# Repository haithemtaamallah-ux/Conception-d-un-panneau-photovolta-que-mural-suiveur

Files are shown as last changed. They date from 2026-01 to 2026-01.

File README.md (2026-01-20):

# Wall-Mounted Photovoltaic Panel Design with Solar Tracking Device

**End-of-Year Project Report**  
**2nd Year Mechanical Engineering**  
**National Engineering School of Tunis (ENIT)**  
**University of Tunis El Manar**  
**Academic Year: 2025/2026**

**Prepared by:**  
- Snoussi Syrine Sara  
- Taamallah Haithem  

**Supervised by:**  
Mr. Jemmali Mohamed

## 📌 Project Context

This project aims to design a **wall-mounted photovoltaic panel** for self-consumption, equipped with a **single-axis solar tracking device** to optimize the panel’s orientation throughout the day and maximize the amount of solar energy harvested.

## 🎯 Main Objectives

- Study the Tunisian energy context and the operation of photovoltaic cells  
- Geometrically model the solar path and calculate the angle of incidence  
- Develop Python code to simulate irradiance and annual energy yield for different fixed and tracking inclinations  
- Mechanically design a single-axis tracker actuated by an electric actuator (CAD modeling in CATIA V5)  
- Dimension the components and validate the mechanism’s kinematics  

## 🗂 Repository Structure

*(Details to be added in the GitHub repository)*

## 📊 Detailed Report Content

### 1. Context and Problem Statement
- Current energy situation in Tunisia  
- Structure and operation of a PV cell  
- Effect of the incidence angle on energy production  

### 2. Numerical Modeling and Simulation
- Geometrical model of solar movement (declination δ, hour angle ω)  
- Calculation of incidence angle θ  
- Python algorithm + validation of results  
- Annual energy comparison: fixed vs. tracking panel (different β values)  

### 3. Mechanical Design of the Tracker
- Choice of tracker type: single-axis (rotation β)  
- Kinematic solutions studied:  
  - Motors / couplings  
  - Rack and pinion  
  - Pulley-belt systems  
  - **Electric actuator + linkages** (selected solution)  
- Overall panel and mechanism sizing  
- Detailed 3D modeling in CATIA V5  
- Exploded views, assemblies, functional clearances  

## 🛠 Technologies & Tools Used

- **CAD**: CATIA V5  
- **Programming**: Python (numpy, matplotlib, astronomical calculations)  
- **Key Concepts**: Direct/diffuse radiation, solar tracking, kinematics, mechanical sizing  

## Project Visual Overview

<p align="center">
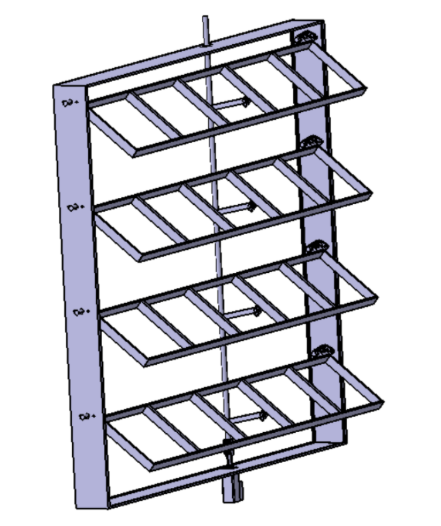
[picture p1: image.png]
Overall system diagram
  
  <br><em>Overall diagram of the panel with single-axis tracker</em>
</p>

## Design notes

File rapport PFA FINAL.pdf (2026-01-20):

République Tunisienne
Ministère de l’Enseignement Supérieur et de la Recherche Scientifique Université de Tunis El Manar École Nationale d’Ingénieurs de Tunis

# Rapport de Projet De Fin D’année

## Conception d’un panneau photovoltaïque mural avec dispositif suiveur

Elaboré par :

### Snoussi Syrine Sara

### Taamallah Haithem

Encadré par :

### MR. Jemmali Mohamed

2

### ème Année Génie Mécanique

Année universitaire : 2025/2026

Projet De Fin D’année

# Remerciements

Nous tenons à exprimer nos sincères remerciements à Monsieur Jemmali Mohamed pour son encadrement attentif et ses conseils précieux tout au long de ce projet. Sa disponibilité, son expertise technique et sa capacité à nous guider avec clarté ont grandement facilité notre progression. À chaque étape, il a su nous orienter, nous apportant des retours pertinents qui nous ont permis de surmonter les obstacles rencontrés et d’affiner notre travail.
Son approche alliant rigueur et bienveillance a créé un environnement propice à l’apprentissage et à l’autonomie, tout en renforçant notre confiance face aux défis techniques. Nous lui sommes profondément reconnaissants pour son investissement et la confiance qu’il nous a témoignée.
Nous remercions également l’École Nationale d’Ingénieurs de Tunis (ENIT) pour nous avoir offert cette opportunité enrichissante, qui nous a permis de consolider nos compétences et d’explorer des domaines techniques variés dans un cadre concret et stimulant.

I

Projet De Fin D’année

# Table des matières

Remerciements | I
Table des figures | IV
Introduction | 1
1 Contexte et problématique | 2

2 Optimisation de la récupération d’énergie solaire : Modélisation,
Analyse et Simulation Numérique | 9

2.3 Mise en œuvre numérique et Analyse

2.3.3 | Energie annuelle récupérable pour différentes configurations | 27
3 Conception et intégration du dispositif suiveur | 29

II

Projet De Fin D’année

3.3.3 | Dimensionnement du dispositif de transformation de mouve-
Conclusion | 50
Annexe | 51
Bibliographie | 55
Bibliographie | 55

III

Projet De Fin D’année

# Table des figures

1.1 Puissance installée pour l’autoconsommation solaire PV [1] | | 3
1.2 Structure d’une cellule PV [3] | | 4
1.3 Effet photovoltaïque sur une cellule PV [4] | | 5
1.4 Principe angle d’incidence | | 6
1.5 Angle d’incidence en fonction de β et γ [5] | | 7
2.1 Mouvement de la terre autour du Soleil [6]. | | 10
2.2 Variation de l’angle horaire [5] | 11
2.3 Variation de l’angle de déclinaison [5] | 12
2.4 Système de coordonnées de la surface terrestre pour un observateur
à Q [5] | 14
2.5 Système de coordonnées centré sur la Terre pour le vecteur directionnel du rayon solaire défini en termes de l’angle horaire (ω) et de
l’angle de déclinaison (δ) [5] | 15
2.6 Vue composite des Figures 2.4 et 2.5 [5] | 17
2.7 Angle d’incidence [5] | 17
2.8 Les différents types de rayonnement solaire [8] | 19
2.9 L’évolution du l’irradiance directe [7] | 21
2.10 Comparaison des azimuts en fonction du temps local pour différentes
dates | 25
2.11 Comparaison des élévations en fonction du temps local pour diffé-
rentes dates | 25
2.12 Comparaison des cos(θ) en fonction du temps local pour différentes
dates | 26
2.13 Comparaison des intensités en fonction du temps local pour diffé-
rentes dates | 26
3.1 Schéma global du systeme | 30
3.2 Schéma cinématique de la solution avec Moteurs-accouplements . . 31
3.3 Schéma cinématique de la solution avec crémaillère-pignons | 32
3.4 Schéma cinématique de la solution avec poulies-courroies | 32

IV

Projet De Fin D’année

3.5 Schéma cinématique de la solution avec Vérin électrique et biellettes 33
3.6 Schéma global du panneau avec suiveur à 1 axe | 34
3.7 Courbe représentative de cos(θ) dans le cas où β = 45◦
| 36
3.8 Courbe représentative de l’Angle d’incidence dans le cas où β = 45◦ 37 3.9 Courbe représentative de cos(θ) dans le cas où β = 50◦
| 38
3.10 Courbe représentative de l’Angle d’incidence dans le cas où β = 50◦ 38 3.11 Calcul des paramètres du panneau en fonction du déplacement x . . 39
3.12 Solution en CATIA | 42
3.13 châssis | 43
3.14 Support | 43
3.15 Palier à rotule | 44
3.16 Vérin électrique | 45
3.17 fourchette filetée et embout à rotule | 45
3.18 Liaison linéaire annulaire | 46
3.19 Liaison rotule | 46
3.20 jeu fonctionnel | 46
3.21 Mécanisme de la solution | 47
3.22 guidage en translation | 47
3.23 vue éclatée de l’ensemble | 48
3.24 Panneau au cours de la journée | 48
3.25 Panneau au repos | 49

V

Projet De Fin D’année

# Introduction Générale

En raison des enjeux liés au changement climatique et de l’urgence de changer nos modes de consommation énergétique, l’ingénieurie moderne est essentielle pour la transition vers des solutions durables.

Dans ce contexte, l’utilisation pertinente de l’énergie solaire ne se limite pas à une avancée technologique, mais constitue une réponse stratégique aux défis environnementaux, économiques et sociaux actuels.

Ce projet s’aligne parfaitement avec cette approche, ce qui nous a amené à réaliser d’abord une étude approfondie du rayonnement solaire en Tunisie selon les différentes orientations possibles. Sur la base de cette analyse, nous avons ensuite étudié et comparé plusieurs solutions afin de proposer une conception permettant de maximiser l’apport de l’énergie solaire.

1

Projet De Fin D’année

# Chapitre 1

# Contexte et problématique

## 1.1 Introduction

Dans un contexte mondial caractérisé par la transition énergétique et la quête de solutions durables , la Tunisie se trouve face à plusieurs défis majeurs vu la dépendance des énergies fossiles en provenance de l’étranger et la demande qui ne cesse d’augmenter d’une année à une autre ce qui nécessite un recourt vers l’énergie renouvelable , notamment l’énergie solaire. Dans ce chapitre , on va tout d’abord analyser par des statistiques la position énergétique actuelle en Tunisie ,ensuite on va se concentrer sur le fonctionnement des panneaux photovoltaïques tout en abordant le phénomène photovoltaïque.

## 1.2 Situation énergétique actuelle

Le secteur énergétique en Tunisie est confronté à plusieurs défis stratégiques, économiques, sociaux et environnementaux.En effet, la production de l’énergie électrique en Tunisie dépend essentiellement de l’énergie fossile, spécialement du gaz naturel qui représente 97% de la production totale, dont la majorité provient de l’étranger.De plus, la demande d’électricité devient de plus en plus importante, augmentant le déficit de la balance énergétique pour atteindre les 50% en 2018. Vu cette situation énergétique, la Tunisie a établi une nouvelle approche énergétique basée sur les ressources renouvelables, cette approche a pour objectif de réduire 30% de sa consommation d’énergie primaire à l’horizon de 2030, dont 15% à partir de l’énergie solaire [1].
Malgré que le marché Tunisien reste peu développé comparé aux pays voisins, il reconnaît une croissance significative ces dernières années, ce diagramme illustre l’évolution des systèmes installées dans un cadre de projet en Tunisie :

2

Projet De Fin D’année

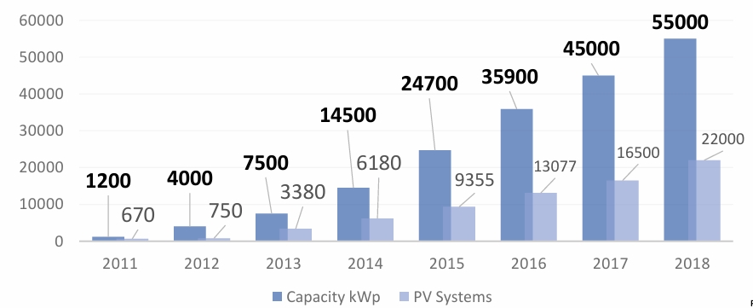
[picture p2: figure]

Figure 1.1 – Puissance installée pour l’autoconsommation solaire PV [1].

Généralement,les panneaux solaires en Tunisie sont concentrés au niveau des sites résidentiels, ces systèmes sont installés au niveau des toits pour avoir un rendement optimal qui peut atteindre 24% pour les cellules en silicium monocristallin.Bien que ces panneaux constituent une solution durable, l’entretien et les coûts élevés des cellules restent encore des défis majeurs actuellement.
Les "panneaux photovoltaïques muraux" peuvent être une solution efficace.En effet, ces systèmes sont caractérisés par : Une facilité d’entretien puisqu’ils sont moins exposés aux facteurs extérieurs (poussières, vent, pluie...), une optimisation de l’espace en exploitant les surfaces verticales inutilisées ce qui convient surtout aux bâtiments résidentiels et une sécurité plus élevée en minimisant le risque de chutes des panneaux en cas de vents violents.

## 1.3 Structure et fonctionnement des panneaux photovoltaïques

### 1.3.1 Structure d’une cellule photovoltaïque :

Les cellules des panneaux photovoltaïques (PV) sont constituées par :
Couche anti-reflet : cette couche sert à assurer un maximum d’absorption des rayons solaires en réduisant la réflexion.
Contacts métalliques : nécessaires pour l’obtention d’un courant continu, il existe deux contacts, un contact avant qui sert à introduire le rayon solaire et un contact arrière pour assurer une bonne conduction du courant.
Une jonction : appelée "jonction PN" formée par l’union de deux couches dopées de manière opposée, comme illustrée dans la Figure 1.2 :

3

Projet De Fin D’année

Une couche N : est une couche semi-conductrice généralement en silicium, on réalise un dopage négatif en introduisant des éléments de type donneur qui possèdent un électron de valence supplémentaire que les silicuim (phosphore (P), l’arsenic (As)...) ce dopage nous permet d’avoir une couche riche en électrons libres. une couche P : est une couche semi-conductrice dopée positivement par le fait d’introduire des éléments receveurs d’électrons (bore(B),Aluminium(Al)...) ce dopage crée un déficit d’électrons qu’on l’appelle ’trous d’électrons’ qui se comportent comme des charges positives [2].
La Figure suivante illustre les différentes composantes d’une cellule PV :

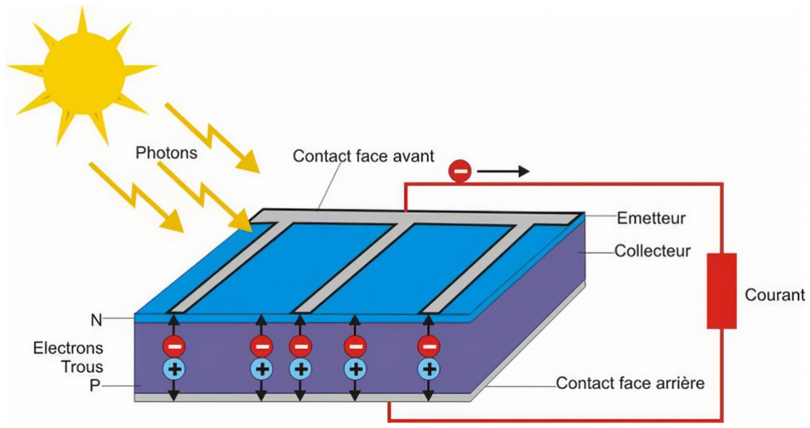
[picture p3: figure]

Figure 1.2 – Structure d’une cellule PV [3].

### 1.3.2 Fonctionnement d’un PV

En absence de rayonnement solaire, c’est-à-dire à l’état initial, et au niveau de la couche P, les éléments introduits pour le dopage positif sont déficitaires en électrons par rapport au silicium (Si) , par conséquence, ils ont tendance à capter des électrons du reste du matériau.
Pour simplifier l’étude, on prend le cas le plus courant qui est le dopage positif avec le bore (B), cet élément est déficitaire par un seul électron par rapport au Si. Une fois qu’un atome de bore a capté un électron, ce dernier laisse derrière lui un trou d’électrons chargé positivement. Ce phénomène se répète de proche en proche et on dit alors que les trous d’électrons se déplacent par diffusion. Lorsque les deux couches sont en contact, il se produit un gradient de concentration entre ces deux matériaux, en effet, les électrons se déplacent de la couche N vers P et de la même

4

Projet De Fin D’année

manière, les trous d’électrons se déplacent de la couche P vers N ,cette diffusion entraine un déséquilibre de charge et conduit à l’apparition d’une charge positive au niveau de la couche N et une charge négative dans la couche p ,par conséquence on obtient une différence de potentiel au niveau de la jonction ce qui induit un champ électrique.
Lorsqu’un photon arrive à la cellule, il transmet une énergie capable d’arracher un électron et par suite la formation de nouveaux trous d’électrons et d’électrons libres qui, à leur tour, ont tendance à trouver leur position de stabilité mais le champ électrique formé au niveau de la jonction va contribuer à la séparation des charges positives et négatives de manière que les électrons seront repoussées vers la couche N et les trous vers la couche P. Les électrons cherchant à se recombiner avec les trous passent alors par le circuit extérieur créant ainsi un courant électrique continu qu’on appelle "photo-courant", les électrons sont délivrés sous la tension créée dans la jonction PN qu’on appelle la "photo-tension", le produit des deux correspond à la puissance électrique délivrée par la cellule qui convertit ainsi directement une partie de l’énergie lumineuse en énergie électrique, avec un rendement qui correspond au produit des deux énergies, traduisant l’efficacité de cette transformation, et une puissance crête qui représente la production maximale en conditions standards. Cependant, les cellules photovoltaïques courantes sont disposées d’une manière plane selon des orientations fixes. Elles ne peuvent pas s’adapter aux variations d’ensoleillement ni aux facteurs extérieurs qui les mettent en danger.
Ces limitations ouvrent la voie à d’autres configurations qui possèdent beaucoup d’avantages, notamment les panneaux photovoltaïques muraux, qui feront l’objet de notre étude.

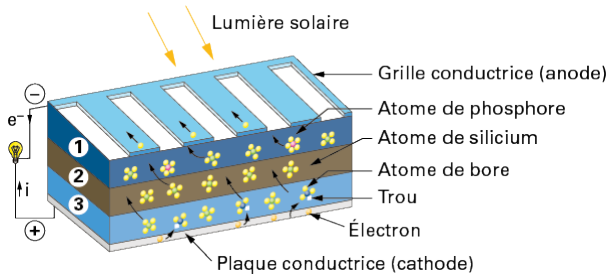
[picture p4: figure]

Figure 1.3 – Effet photovoltaïque sur une cellule PV [4].

5

Projet De Fin D’année

### 1.3.3 Problématique

Les panneaux photovoltaïques peuvent être installés dans différents endroits sous plusieurs configurations. On les trouve généralement sur les toitures inclinées des bâtiments, qu’ils soient industriels ou urbains, intégrés en fonction des contraintes d’espace au sol, ou encore fixés verticalement sur les murs, d’où l’appellation de panneaux photovoltaïques muraux. Cette configuration est moins courante, mais elle offre plusieurs avantages tels que l’accessibilité pour l’entretien, la simplicité d’installation, ainsi qu’une meilleure protection contre les intempéries, notamment le vent et la grêle, qui constituent un problème majeur pour la configuration en toiture. Cependant, leur rendement est très faible, en raison de leur position défavorable pour capter l’énergie solaire, ce qui rend cette solution moins performante.

### 1.3.4 Objectifs

L’objectif essentiel de ce projet consiste à améliorer le rendement d’un panneau Photovoltaïque mural, pour ce faire, il faut tout d’abord identifier les paramètres influençant l’efficacité du panneau.Parmi ces paramètres l’angle d’incidence (θi), mesuré entre les rayons solaires et la normale à la surface, qui joue un rôle clé. la Figure ci-dessous illustre l’effet de l’angle d’incidence sur la surface éclairée :

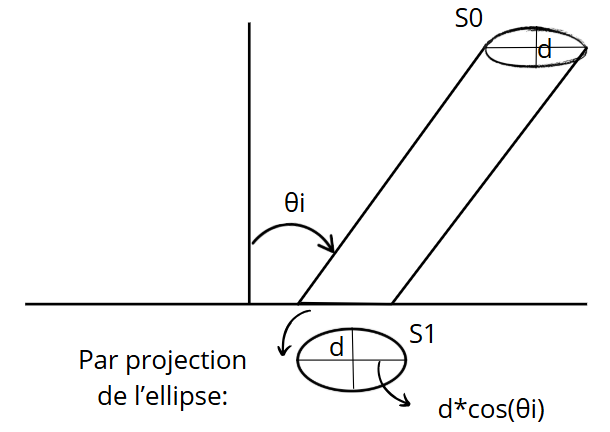
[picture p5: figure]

Figure 1.4 – Principe angle d’incidence.

Nous représentons le rayonnement solaire incident par un faisceau cylindrique de diamètre d, de section

S0 =

πd²
4

La surface éclairée forme alors une ellipse de section

S1 =

πd²
4 cos(θi)

=

S0
cos(θi)

6

Projet De Fin D’année

La densité d’énergie sur la surface du panneau est ainsi plus faible que celle du faisceau incident.
Cette représentation permet de visualiser l’importance de la variation de l’angle d’incidence, qui influence la surface du panneau captivant l’énergie solaire, et donc la quantité d’énergie récupérable. Ainsi, pour améliorer le rendement d’un panneau mural, nous devons trouver une solution permettant d’adapter sa position de manière à minimiser cet angle d’incidence.

## 1.4 Méthodologie adoptée

Afin d’atteindre ces objectifs, nous avons suivi une méthodologie qui com-porte trois étapes en nous focalisant sur l’évolution de cos(θi), qui est un facteur déterminant de l’énergie annuelle récupérable.
Première étape : Nous avons mis en place un modèle qui nous permet d’identifier les paramètres dont l’angle d’incidence dépend. À partir de ce modèle, nous avons pu tirer la conclusion que ce dernier dépend du temps, de la localisation géographique du panneau et de son orientation définie par deux angles : β (angle d’inclinaison par rapport au sol) et γ (l’angle azimutal de la surface). Ce modèle géométrique, que nous allons représenter par le biais d’une figure explicative, constitue la base de calcul de cos(θi).

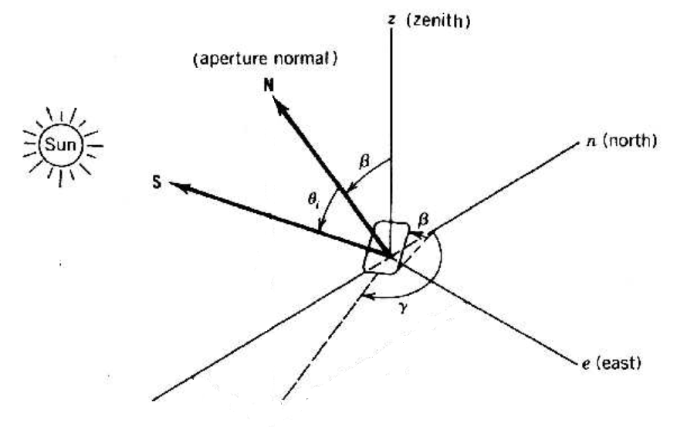
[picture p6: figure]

Figure 1.5 – Angle d’incidence en fonction de β et γ [5]

Deuxième étape : Une fois ce modèle établi, nous avons évalué l’énergie récupérable par an selon trois orientations du panneau : plein sud, sud-est et sud-ouest.

7

Projet De Fin D’année

Ensuite, pour chacune de ces orientations, nous avons cherché l’évolution optimale de β qui maximise l’énergie annuelle.
Ces deux étapes feront l’objet du chapitre deux, où elles seront détaillées en mettant en place un modèle analytique et une simulation numérique réalisée en Python, qui permet de valider les résultats théoriques obtenus.

Troisième étape : Nous avons choisi une solution qui nous permet de maximiser l’énergie annuelle récupérable par notre panneau, et ensuite, nous sommes passés à la conception mécanique à l’aide du logiciel CATIA V5.

8

Projet De Fin D’année

# Chapitre 2

# Optimisation de la récupération

d’énergie solaire : Modélisation,

# Analyse et Simulation Numérique

## 2.1 Introduction

Durant ce chapitre, nous allons proposer une modélisation analytique et numérique pour optimiser l’orientation des panneaux photovoltaïques muraux. L’objectif est de maximiser l’énergie récupérable, donc leur rendement, en ajustant dynamiquement l’angle d’inclinaison en fonction de la trajectoire solaire.

## 2.2 Modèle analytique

Le modèle géométrique présenté ici est classique et est largement reconnu dans l’étude des systèmes solaires. Il est inspiré du livre Power From The Sun de William
B. Stine et Michael Geyer, qui en propose une description claire et rigoureuse [5].

### 2.2.1 Modèle géométrique

Les orbites de la Terre en relation avec le Soleil : Le trajet de la Terre autour du soleil, ce qu’on appelle son orbite, décrit une trajectoire elliptique qui suit un sens antihoraire vu du pole nord . Ce mouvement est périodique et dure plus de 365 jours, soit une année sidérale, à une vitesse de 30km/s . Une année se décompose en quatre périodes saisonnières du a l’inclinaison de l’axe de la Terre, qui modifie notre réception de la lumière solaire.
Ainsi, pendant l’été, l’hémisphère qui est incliné vers le Soleil reçoit plus de lumière, entraînant des journées plus longues et des températures plus chaudes contrairement

9

Projet De Fin D’année

a ce qui se passe en hiver. L’orbite terrestre est caractérisée par des événements remarquables tels que les solstices, les équinoxes et les apsides.
Les solstices représentent les deux moments de l’année où l’inclinaison de la Terre par rapport au Soleil atteint son maximum .On distingue deux solstices : le solstice d’été (21 juin) et le solstice d’hiver (21 décembre)
Les équinoxes se manifestent quand le jour et la nuit ont presque la même durée, en raison de l’orientation de la Terre, dont l’axe de rotation est perpendiculaire à la ligne reliant la Terre et le Soleil. Ils se produisent aux environs du 21 mars et du 23 septembre.
Les apsides désignent les positions de l’orbite elliptique d’un corps céleste, tel que la Terre, où ce dernier se situe soit à la distance minimale : l’aphélie qui se trouve entre le 3 et le 5 juillet, soit à la distance maximale du Soleil : la périhélie qui se situe entre le 2 et le 5 janvier.
Ce sont donc les deux points extrêmes de l’orbite.

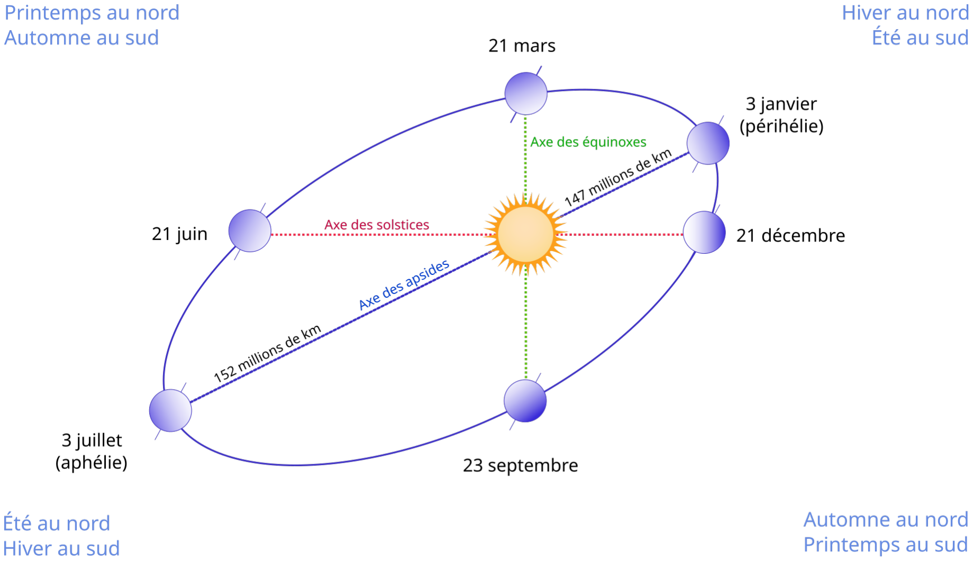
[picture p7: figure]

Figure 2.1 – Mouvement de la terre autour du Soleil [6].

Les variations du mouvement de notre planète agissent sur la durée des jours et des nuits ce qui rend la mesure du temps inconstante. Pour y faire face, un système basé sur le temps moyen a été construit, garantissant une référence universelle.

Angle horaire (ω) et équation du temps : Afin de décrire la rotation de la terre autour de son axe polaire, on introduit la notion de l’angle horaire. Ce dernier correspond à l’angle entre le méridien de l’observateur et celui contenant le soleil. À midi solaire cet angle est nul car le soleil atteint son point le plus haut dans le

10

Projet De Fin D’année

ciel ; c’est le moment ou on dit que le soleil est « au sud » (ou « au nord », dans l’hémisphère sud) car le soleil appartient au plan méridien de l’observateur. Ensuite il augmente de 15° par heure.
Le calcul de l’angle horaire est en relation avec le temps solaire qui est un concept utilisé pour prédire la direction des rayons solaires par rapport un point donné sur la terre donc il dépend principalement de la localisation et il est d’une manière générale différent de l’heure locale qui est définie par les fuseaux horaires.

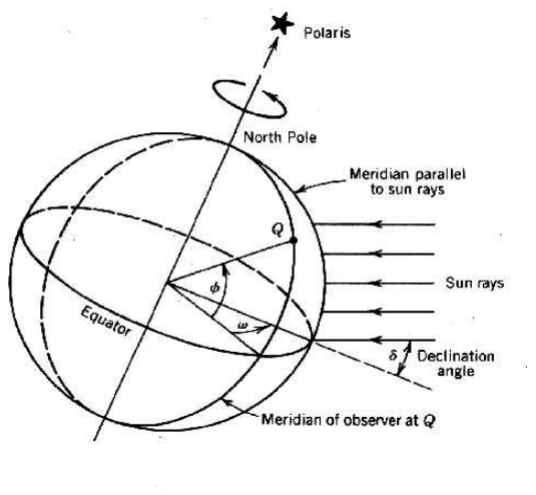
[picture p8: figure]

Figure 2.2 – Variation de l’angle horaire [5].

Cette relation est mise en œuvre à travers l’équation qui suit :

W = 15 × (ts − 12) | (2.2.1)

Comme mentionné précédemment dans le paragraphe sur les orbites de la Terre en relation avec le Soleil, notre planète ne se déplace pas de manière uniforme ce qui conduit à la définition de l’équation du temps (EOT) qui représente la différence entre le temps solaire moyen, qui est une estimation régulière du temps en supposant que la Terre se déplace à une vitesse constante sur une trajectoire circulaire, et le temps solaire vrai, qui prend en compte la véritable position de la Terre sur son orbite à un moment précis. Cette notion de l’équation du temps est primordiale pour permettre une conversion juste entre le temps solaire et l’heure locale (LCT) ,en prenant bien évidement en considération l’emplacement, le jour de l’année et les normes locales auxquelles les horloges locales sont réglées.

11

Projet De Fin D’année

EOT = 0.258 cos x − 7.416 sin x − 3.648 cos 2x − 9.228 sin 2x | (2.2.2)

où la variable x est calculée en fonction du jour de l’année N j (avec N j = 1 pour le 1er janvier) :

x =

360(N j − 1)
365.242 | (2.2.3)

L’équation de l’heure locale prend la forme suivante :

LCT = ts −

EOT
60
+ LC + D | (2.2.4)

D est un paramètre qui adapte l’heure selon celle de l’été et LC est la correction définie par :

LC =

local longitude − longitude du méridien de temps standard 15

(2.2.5)

Angle de déclinaison (δ) : L’angle de déclinaison est celui mesuré entre une ligne reliant le centre de la Terre à celui du soleil et un plan dit plan équatorial qui contient l’équateur de la Terre .
Au solstice d’été (vers le 21 juin), l’angle de déclinaison atteint +23,45°, avec le Soleil au point le plus haut dans le ciel de l’hémisphère nord.
Pendant les équinoxes (autour du 22 mars et du 23 septembre), l’angle de déclinaison est nul, et le jour et la nuit durent chacun 12 heures.

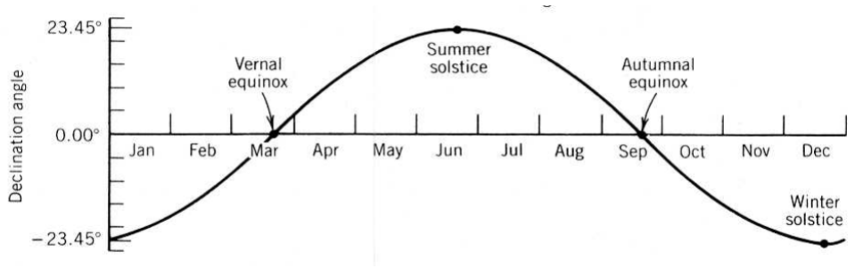
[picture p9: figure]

Figure 2.3 – Variation de l’angle de déclinaison [5].

12

Projet De Fin D’année

Angle d’élévation (α) et Azimuth (A) : Quand un observateur regarde le Soleil depuis un endroit quelconque sur la planète, il désire toujours définir ses coordonnées par rapport à un repère local, et non dans un système géocentrique. On a donc suivi une démarche précise pour convertir la position du Soleil d’un repère contenant le centre de la Terre à un repère local.
On définit dans toute la suite :
— Le repère géocentrique : les axes sont définis comme suit :
— p : axe polaire, aligné avec l’axe de rotation de la Terre.
— e : axe est-ouest, appartenant au plan équatorial.
— m : axe méridien qui appartient à l’équateur au méridien de l’observateur. La position du Soleil est définie dans ce repère en fonction de l’angle horaire (ω) et de l’angle de déclinaison (δ).
— Le repère local :
— L’axe z est vertical et pointe vers le zénith.
— L’axe e est orienté vers l’est.
— L’axe n est orienté vers le nord.
Le passage d’un repère à l’autre est réalisé via une rotation autour de l’axe e d’un angle égal à la latitude (ϕ) de l’observateur.
Dans toute la suite, nous avons pris en compte des hypothèses bien déterminées : — Puisque la distance Terre-Soleil est très grande (environ 23 525 fois le rayon terrestre), la différence entre la position du Soleil vue depuis un lieu quelconque sur Terre et depuis le centre de la Terre n’est pas significative. Ainsi, nous avons négligé dans notre modèle les translations dues à la position de l’observateur.
— L’effet de réfraction atmosphérique est ignoré.
— Tous les angles sont mesurés par rapport au rayon solaire central.
— L’azimut est pris du nord au sud et, par conséquent, le sens horaire est considéré comme positif.
La position du Soleil est définie à l’aide de deux angles : l’angle d’altitude solaire (α), qui se situe entre le rayon solaire central et un plan horizontal contenant l’observateur, et l’angle zénithal solaire.
θz = 90◦ − α | (2.2.6)

13

Projet De Fin D’année

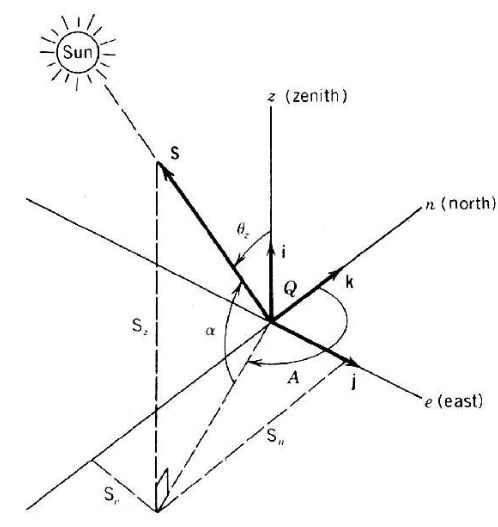
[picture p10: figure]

Figure 2.4 – Système de coordonnées de la surface terrestre pour un observateur à Q [5].

Afin de déterminer les angles d’élévation et d’Azimut, on doit définir un vecteur unitaire qui pointe vers le Soleil à la surface de la Terre, puis nous le transférerons au centre de la Terre dans un autre système de coordonnées. Définissons donc S qui est le vecteur unitaire orienté vers le Soleil depuis la position de l’observateur Q :

S = Szi + Sej + Snk | (2.2.7)

Où i,j et k sont les vecteurs unitaires selon les axes z (zenith), e (est-ouest) et n (nord-sud) respectivement. Les cosinus directeurs de S par rapport à ces axes sont Sz, Se et Sn, et s’expriment en fonction de l’altitude α et de l’azimut solaire A :

Sz = sin(α), | Se = cos(α) sin(A), | Sn = cos(α) cos(A).

14

Projet De Fin D’année

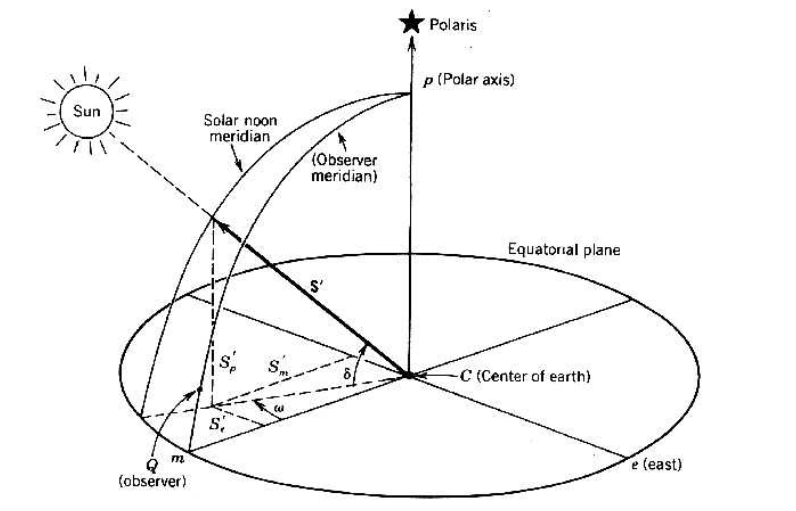
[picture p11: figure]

Figure 2.5 – Système de coordonnées centré sur la Terre pour le vecteur directionnel du rayon solaire défini en termes de l’angle horaire (ω) et de l’angle de déclinaison (δ) [5].

Faisons maintenant le passage au repère géocentrique, définissons donc le vecteur directionnel S’ pointant vers le Soleil :

S

′ = S

′
mum + S

′
eue + S

′
pup | (2.2.8)

Avec um, ue et up sont les vecteurs unitaires des axes m,e et p respectivement. Voici l’écriture matricielle qui illustre ce passage :

Sz
Se
Sn

- =

cos φ | 0 sin φ
0 | 1 | 0
− sin φ 0 cos φ

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
- (2.2.9)

Passons maintenant à la résolution du système matriciel :

Sz = S

′
m cos φ + S

′
p

sin φ
Se = S

′
e
Sn = S

′
p

cos φ − S

′
m sin φ

(2.2.10)

Si on remplace Sz, Se , Sn ,S

′
m, S

′
p

et S

′
e par leurs expressions on obtient :
sin α = sin δ sin φ + cos δ cos ω cos φ | (2.2.11)
cos α sin A = − cos δ sin ω | (2.2.12)
cos α cos A = sin δ cos φ − cos δ cos ω sin φ | (2.2.13)

15

Projet De Fin D’année

Et finalement on aura l’équation qui illustre l’élévation :

α = sin⁻¹
(sin δ sin φ + cos δ cos ω cos φ) | (2.2.14)

On cherche maintenant à déterminer l’azimut. Celui-ci peut se présenter par deux expressions équivalentes, présentées ci-dessous, en fonction de l’heure avant ou après le midi solaire et de sa position par rapport à la ligne est-ouest (au nord ou au sud).

A

′ = sin⁻¹
−

cos δ sin ω
cos α

!
| (2.2.15)

Conditions pour le calcul de l’angle azimutal A :

— Si cos ω ≥

tan δ
tan φ

!
, alors :

A = 180◦ − A

′ | (2.2.16)

— Sinon (cos ω <

tan δ
tan φ

!
) :

A = 360◦ + A

′ | (2.2.17)

Méthode alternative de calcul :

A

′′ = cos⁻¹

sin δ cos φ − cos δ cos ω sin φ cos α

!
| (2.2.18)

Conditions pour cette méthode : — Si sin ω > 0 :
A = 360◦ − A
′′ | (2.2.19)

— Sinon (sin ω ≤ 0) :
A = A
′′ | (2.2.20)

16

Projet De Fin D’année

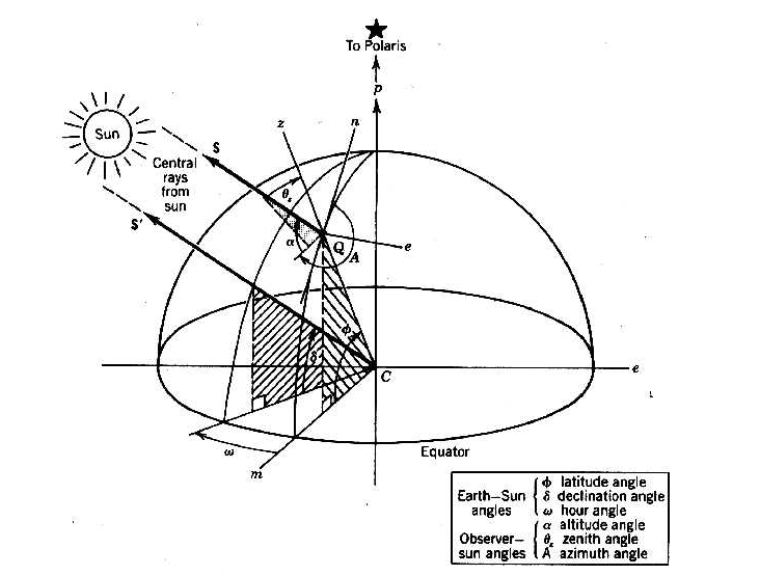
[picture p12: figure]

Figure 2.6 – Vue composite des Figures 2.4 et 2.5 [5].

Angle d’incidence solaire : Dans le développement de systèmes d’énergie solaire, il est nécessaire de calculer l’angle entre les rayons solaires et un vecteur normal à la surface du dispositif qui capte ces rayons. Cet angle est appelé l’angle d’incidence et représente un élément clé pour la suite de notre étude.

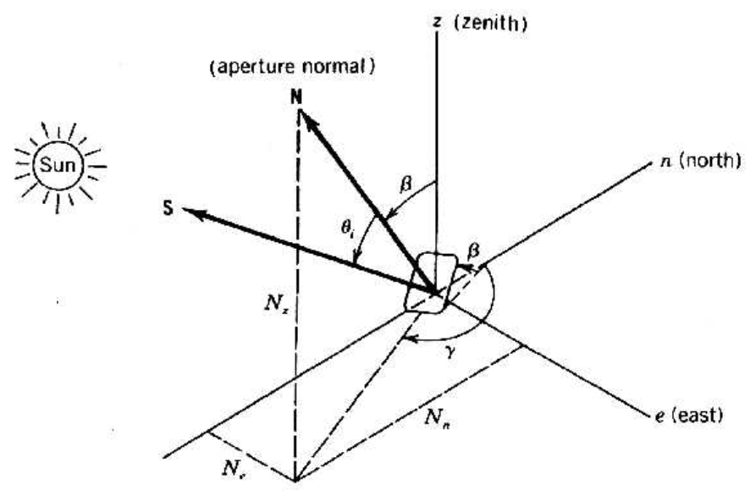
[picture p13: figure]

Figure 2.7 – Angle d’incidence [5].

Pour le calcul de ce dernier, nous avons effectué le produit scalaire des 2 vecteurs unitaires : le vecteur S qui pointe vers le soleil et la normale au plan du dispositif :

17

Projet De Fin D’année

N Avec les cosinus directeurs du vecteur N définis par :

Nz = cos β | (2.2.21)
Ne = sin β sin γ | (2.2.22)
Nn = sin β cos γ | (2.2.23)

Réalisons le produit scalaire :

cos θi = S · N | (2.2.24)

Remplaçons par les cosinus directeurs du vecteur S et ceux de N ,nous obtenons l’équation décrivant l’angle d’incidence solaire :

cos θ = sin α cos β + cos α sin β cos(γ − A) | (2.2.25)

où :
— β est l’angle que fait le dispositif récepteur avec le sol — α est l’altitude solaire
— γ est l’angle azimutal de la surface
— A est l’azimut solaire

Calcul de l’irradiation globale : Dans les systèmes d’exploitation de l’énergie solaire, le besoin d’estimer l’irradiation globale est nécessaire pour la conception et le développement de ces systèmes, ainsi que dans l’évaluation de leurs performances. Le modèle de Capderou est abordé en 1987, c’est une méthodologie qui est basée sur la connaissance du trouble atmosphérique afin de déterminer les différentes composantes du rayonnement solaire d’un site bien précis [7].
L’irradiation globale est définie par la somme de deux composantes : composante directe et composante diffuse.
G = I + D | (2.2.26)

où :
— I :composante directe.
— D :composante diffuse.

composante directe : c’est le rayonnement qui atteint la surface d’une manière directe sans être dévié ou diffus par l’atmosphère, il est intense et atteint son maximum lorsque le ciel est clair (pas de nuages, de pollution...)

18

Projet De Fin D’année

Composante diffuse : c’est un rayonnement qui est diffus dans l’atmosphère et arrive à la terre avec différents angles. Ce type de rayonnement est présent même lorsqu’il y a des nuages dans le ciel. Contrairement au rayonnement direct, il ne suit pas une trajectoire unique.
Cette Figure illustre les différents types de rayonnement :

Figure 2.8 – Les différents types de rayonnement solaire [8].

Dans la suite, on s’intéressera seulement à la composante directe et, par conséquent, on va négliger la partie diffuse du rayonnement. Comme indiqué précédemment, les calculs dans le modèle de Capderou sont basés essentiellement sur les facteurs de troubles atmosphériques, ce qui nous amène à définir le facteur de trouble de Linke. Le facteur trouble de Linke suppose que le ciel est clair et résulte de la sommation des facteurs liés aussi aux troubles atmosphériques, en effet il est défini par l’équation suivante :

TL = T0 + T1 + T2 | (2.2.27)

où :

— T0 : C’est le trouble lié à l’absorption gazeuse (l’ozone et la vapeur d’eau), dont les concentrations sont variables. Ce facteur est donné par l’équation suivante, en intégrant les paramètres astronomiques terrestres :

T0 = 2,4−0,9 sin(φ)+0,1 (2 + sin(φ)) Ahe−0,2z−(1,22 + 0,14Ahe) (1−sin(α))
| (2.2.28)
où :
— z : l’altitude du site (en km),
— Ahe : l’alternance hiver-été définie par :

Ahe = sin

360
365
- (N − 121) | (2.2.29)

avec :

19

Projet De Fin D’année

— N : le jour de l’année (de 1 à 365).

— T1 : C’est le trouble lié à l’absorption par les gaz de l’atmosphère tels que le CO2, O2 et O3, ainsi qu’à la diffusion de Rayleigh. Son équation est illustrée ci-dessous :

T1 = (0,89)z
(2.2.30)

— T2 : Ce terme est relatif à la diffusion par les aérosols avec une légère absorption. il est défini par :

T2 = (0,9 + 0,4Ahe) (0,63)z (2.2.31)

Une fois que le facteur de trouble de Linke (Tl) est déterminé, on peut introduire l’équation de l’irradiance directe sur un plan horizontal :

I = I0 sin(α) exp

−Tl

·

"
0,9 +

9,4.sin(α)
(0,89)z

#−1

(2.2.32)

où :
— I0 : l’irradiance solaire extra-atmosphérique mesurée par unité de surface, avec une valeur de 1367 W/m²
,
— α : l’angle d’élévation du soleil,
— Tl

: le facteur de trouble de Linke.

L’irradiance directe reçue sur un plan incliné, en fonction de l’orientation et de l’inclinaison, est donnée par l’équation suivante :

Iα = I0 cos(θ) exp

−Tl

·

"
0,9 +

9,4.sin(α)
(0,89)z

#−1

(2.2.33)

où :
— θ : l’angle d’incidence.
La Figure suivante montre les valeurs de l’évolution de l’irradiance directe mesurés et ceux du modèle de Capdreou par ciel clair à Alger lors des différents mois :

20

Projet De Fin D’année

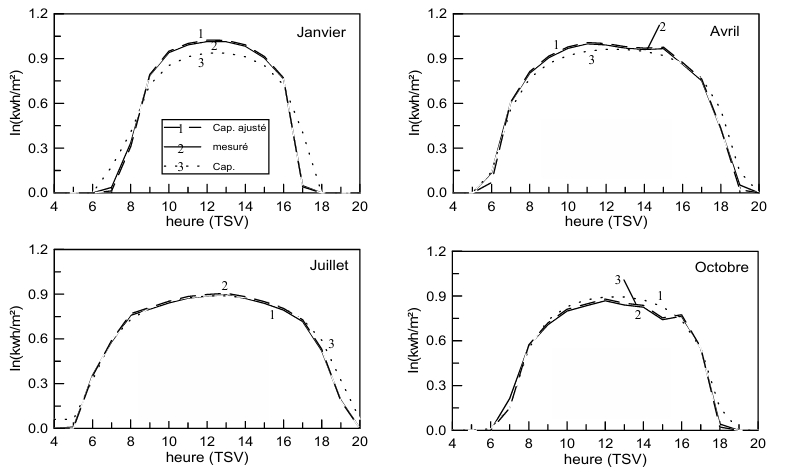
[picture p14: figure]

Figure 2.9 – L’évolution du l’irradiance directe [7].

En se basant sur les résultats fournis,on constate un léger écart entre les valeurs réelles mesurées et les valeurs théoriques calculés par le modèle de Capderou par conséquence on peut adopter ce modèle pour les calculs nécessaires et la recherche de la solution.

Recherche mathématique de βoptimale :

Objectif : Maximiser cos θi pour déterminer la valeur optimale de l’inclinaison β du panneau solaire.

Expression de cos θi :

cos θi = sin α cos β + cos α sin β cos(γ − A) | (2.2.34)

Changement de variable : En posant

a = sin α et b = cos α cos(γ − A) | (2.2.35)

on peut réécrire cos θi sous la forme : f(β) = √
a

2 + b

2

(cos ζ cos β + sin ζ sin β) | (2.2.36)

=

√
a

2 + b

2 cos(β − ζ) | (2.2.37)

où

ζ = arctan

b
a

!
| (2.2.38)

21

Projet De Fin D’année

La fonction f(β) est maximale lorsque cos(β − ζ) est maximal, c’est-à-dire égal à 1.

La valeur optimale de béta s’écrit alors :

β ≡ arctan

cos α cos(γ − A)
sin α

!
mod 2π | (2.2.39)

## 2.3 Mise en œuvre numérique et Analyse des configurations :

### 2.3.1 Algorithme et code de calcul Python

Afin d’exploiter le modèle analytique établi qui nous permet de rechercher l’angle d’inclinaison β optimal maximisant l’énergie annuelle récupérable, une mise en œuvre numérique a été réalisée à travers un algorithme qui servira ensuite dans la simulation en Python capable d’identifier la meilleure orientation du panneau selon les différentes configurations.
L’algorithme établi est illustré ci-dessous :

22

Projet De Fin D’année

Algorithm: Calcul de l’énergie solaire reçue annuelle

### 1. Initialisation

Définir la latitude, longitude, altitude du site Définir l’inclinaison et orientation du panneau Définir le mode : fixe ou suiveur

### 2. Pour chaque jour de l’année (1 à 365)

Calculer le numéro du jour
for chaque heure de 0h à 24h do
Calcul de l’équation du temps
Calcul du temps solaire véritable
Calcul de l’angle horaire
Calcul de la déclinaison solaire
Calcul de l’élévation et de l’azimut solaire end

### 3. Calcul des Troubles atmosphériques

Calculer Ahe
Calculer T0, T1, T2 en fonction de l’altitude et de α Déduire Tl = T0 + T1 + T2

### 4. Pour chaque heure, si α > 0

Calculer ILi

### 5. Calcul du cosinus de l’angle d’incidence θ

if mode fixe then
β est constant
end
else if mode suiveur then
β est ajusté dynamiquement pour optimiser l’angle end

### 6. Calcul de l’intensité inclinée

ILinc = ILi

- cos(θ)

### 7. Intégration journalière

Intégrer numériquement l’énergie reçue par jour

### 8. Accumulation annuelle

Additionner les énergies journalières
Convertir en kWh
L’algorithme présenté ci-dessus a été implémenté en Python. Le code source complet est disponible en Annexe.
L’énergie EL récupérable au cours d’une année est obtenue par un calcul d’intégrale de l’irradiation sur une année présenté ci-dessous :

EL =

Z T

0

IL(γ, β, t) dt =

X

365

j=1

EI (γ, β, j)

23

Projet De Fin D’année

— EL : énergie totale récupérable sur une année pour 1 m² de cellules (et non de panneau) et une localisation L(p, longitude).
— IL(γ, β, t) : la puissance surfacique instantanée récupérable par une cellule de normale définie par γ et β.
— T : durée d’une année en secondes (24 × 3600 × 365 = 31 536 000 s).
— L : localisation du lieu définie par la longitude par rapport à Greenwich et la latitude par rapport à l’équateur.
— EI (γ, β, j) : énergie totale récupérable sur la journée j (j ∈ {1, 2, . . . , 365}) pour 1 m² de cellules (et non de panneau) et une localisation L.

EI (γ, β, j) = Z j×Tl

(j−1)×Tl

IL(γ, β, t) dt =

Z ts=24

ts=0

IL(γ, β, j, ts) dts

— IL(γ, β, j, ts) : la puissance surfacique instantanée récupérable par une cellule de normale définie par γ et β en fonction de l’heure solaire pour une journée j.
— T

′ = 24 × 3600 secondes.
— t : temps en secondes s’écoulant sur l’année.
— ts : temps solaire en heures pour la journée j (ts ∈ [0, 24]).

### 2.3.2 Premiers résultats et vérification du code développé

Afin de vérifier le code développé, nous avons commencé par tracer l’évolution de l’azimut et de l’élévation solaires pour deux journées particulières (21 juin et 21 décembre) en considérant la configuration classique d’un panneau orienté plein sud (gamma=180°) et incliné à 45°(béta=45°).
Les courbes d’azimut obtenues sont présentées dans la Figure ci-après.

24

Projet De Fin D’année

(a) Azimut le 21 juin (γ = 180◦
) | (b) Azimut le 21 janvier (γ = 180◦
)

Figure 2.10 – Comparaison des azimuts en fonction du temps local pour différentes dates

On constate que l’azimut, le 21 juin à midi (12h), est à 180°. La courbe est symétrique autour du midi et la variation de l’azimut est lente, ce qui indique que la trajectoire solaire est plus longue et plus haute en été. Tandis que le 21 janvier, la variation autour de 180° est plus marquée et on atteint seulement 250° comme valeur maximale, traduisant le fait que la trajectoire en hiver est plus basse et que la durée de la journée est plus courte.
La Figure 2.11 présente les courbes d’élévation obtenues pour les deux journées du 21 juin et 21 décembre.
(a) Élévation le 21 juin (γ = 180◦

) (b) Élévation le 21 janvier (γ = 180◦ )

Figure 2.11 – Comparaison des élévations en fonction du temps local pour différentes dates

25

Projet De Fin D’année

En été, le Soleil atteint son point le plus haut vers midi, avec une élévation qui atteint environ 77°, tandis que durant le solstice d’hiver (21 janvier), l’élévation est beaucoup plus faible, autour de 33°; cette différence s’explique par l’inclinaison de l’axe de rotation de la Terre, qui modifie l’angle d’ensoleillement selon les saisons et, par conséquent, la durée des journées.
Après la vérification de la cohérence des résultats pour l’azimut et l’élévation, nous avons tracé les courbes de cos(θ) :
(a) Courbe de cos(θ) le 21 juin | (b) Courbe de cos(θ) le 21 janvier

Figure 2.12 – Comparaison des cos(θ) en fonction du temps local pour différentes dates

Le 21 juin, la valeur de cos(θ) est élevée sur une grande partie de la journée, traduisant un bon alignement du rayonnement solaire avec la normale à la surface . Le 21 janvier, cos(θ) reste faible, limitant la quantité d’énergie captée.
En exploitant le code développé, nous avons tracé les courbes des intensités :
(a) Intensité le 21 juin (γ = 180◦
) | (b) Intensité le 21 janvier (γ = 180◦
)

Figure 2.13 – Comparaison des intensités en fonction du temps local pour différentes dates

26

Projet De Fin D’année

L’intensité lumineuse est plus importante et étalée durant la journée du 21 juin, traduisant une meilleure captation d’énergie solaire. En hiver, le 21 janvier, l’intensité reste faible et concentrée autour de midi, impactant négativement la production solaire.

### 2.3.3 Energie annuelle récupérable pour différentes configurations

Afin de réaliser notre objectif principal, qui consiste à maximiser l’énergie annuelle récupérée par notre panneau photovoltaïque mural, nous avons analysé multiples configurations qui correspondent à différentes orientations du panneau avec et sans suiveur.
Pour chaque configuration, l’énergie annuelle récupérable est calculée pour analyser l’intérêt du dispositif suiveur et son apport.
Dans un premier lieu, nous avons traité le cas où les cellules du panneau sont inclinées de 45°, correspond à une configuration classique en toiture.
Les résultats sont présentés d’une manière comparative dans les deux tableaux ci-dessous :
Orientation | Plein sud (γ = 180◦ ) | Sud-est (γ = 135◦ ) | Sud-ouest (γ = 225◦ )
β = 90◦ | 1397.59 | 1367.78 | 1367.17
β(t) | 2679.53 | 2743.81 | 2743.25
% d’apport/au fixe | 91.7% | 100.45% | 100.65%

Table 2.1 – Comparaison de la solution β(t) avec un panneau mural fixe (β = 90◦
)
Orientation | Plein sud (γ = 180◦ ) | Sud-est (γ = 135◦ ) | Sud-ouest (γ = 225◦ )
β = 45◦ | 2405.89 | 2227.37 | 2227.37
β(t) | 2679.53 | 2743.81 | 2743.25
% d’apport/au fixe | 11.3% | 23.18% | 23.11%

Table 2.2 – Comparaison de la solution β(t) avec un panneau sur un toit fixe (β = 45◦
)

Cas mural (β = 90◦
) :
La différence entre β fixe et β(t) est significative. En orientation sud, le panneau fixe capte 1397.59 kWh contre 2679.53 kWh avec β(t), soit un gain de 91.7 %. Ce gain dépasse 100 % en orientation sud-est et sud-ouest. Cela s’explique par le mauvais alignement angulaire en configuration murale, qui est corrigé par le suivi.

27

Projet De Fin D’année

Cas sur toit (β = 45◦
) :
Le rendement est déjà élevé pour le fixe (ex. 2405.89 kWh en orientation sud), donc le gain relatif avec β(t) est bien moindre : seulement 11.3 %. En orientations sud-est et sud-ouest, le gain est un peu plus élevé ( 23 %) mais reste modeste.

Conclusion :
Le cas suiveur (β(t)) s’est révélé très avantageux, notamment en comparaison avec un panneau mural fixe (β = 90◦
), avec une amélioration nette du rendement énergétique. Bien que le gain soit moins significatif par rapport à un panneau incliné sur un toit fixe (β = 45◦
), il est important de souligner que ce dernier présente des contraintes liées à l’exposition aux facteurs environnementaux (vent, neige, grêle, etc.). Ces conditions nécessitent un entretien régulier pour garantir la sécurité et la durabilité des cellules photovoltaïques. Le système à suivi offre donc un bon compromis entre performance énergétique et sécurité.
Remarque :
Dans le cas du suiveur solaire (β(t)), un résultat inattendu a été observé. Cette anomalie pourrait être due à une erreur ou une imprécision dans le code de simulation, et mériterait une vérification approfondie.

28

Projet De Fin D’année

# Chapitre 3

# Conception et intégration du dispositif suiveur

## 3.1 Introduction

Ce chapitre présente la conception du dispositif suiveur qui permet l’optimisation de l’inclinaison du panneau photovoltaïque mural.
Après avoir comparé les différentes solutions de principe , la plus adaptée est développée et modélisée sous CATIA, en se focalisant sur le dimensionnement et la simplicité mécanique du système en expliquant les solutions technologiques adaptées.

## 3.2 Solutions de principe :

### 3.2.1 Type du suiveur :

La solution optimale à retenir est celle intégrant un dispositif suiveur. Maintenant, nous devons décider de suivre uniquement l’élévation du soleil, donc de contrôler l’angle bêta (S1), ou de suivre selon 2 axes, donc contrôler l’angle bêta et gamma (S2).
Le choix a été effectué en tenant compte des avantages et des inconvénients des 2 solutions proposées qui sont présentés dans le tableau ci-dessous :

29

Projet De Fin D’année

Critère | Solution S1 : Suivi sur 1 axe (β) | Solution S2 : Suivi sur 2 axes (β et γ)
Avantages (+) | + Moins de composants et donc de liaisons cinématiques + Moins d’actionneurs + Moins lourd | + Plus d’énergie récupérable + Meilleure orientation mécanique (suivi plus précis du soleil sur deux plans)
Inconvénients (–) | – Moins d’énergie récupérable | – Plus d’actionneurs – Plus de composants et de liaisons cinématiques – Plus complexe (commande, mon-tage, maintenance)

Table 3.1 – Comparaison entre les deux solutions de suivi solaire

En analysant ce tableau, et afin d’établir un compromis entre performance et simplicité nous avons retenu la solution S1, maintenant nous allons présenter et étudier le développement de cette solution cinématiquement.

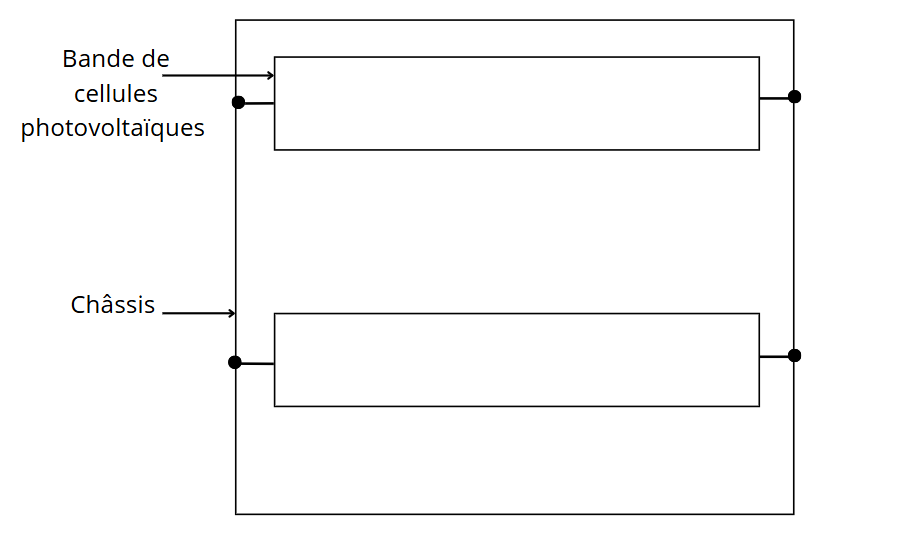
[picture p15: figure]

Figure 3.1 – Schéma global du systeme

Le schéma global présente un châssis rigide sur lequel sont fixées des bandes de cellules photovoltaïques. Ces bandes sont orientables grâce à un dispositif de commande de l’angle β , permettant d’adapter leur inclinaison en fonction de l’élévation du soleil afin d’optimiser la captation de l’énergie solaire.

### 3.2.2 Choix du dispositif de contrôle de β

Après avoir choisi la solution S1, nous avons analysé diverses solutions techniques pour concevoir le dispositif suiveur à 1 axe. Le but était d’identifier la solution la

30

Projet De Fin D’année

plus efficace , tout en minimisant la complexité mécanique. Quatre options ont été étudiées :
— Solution S11 : Consiste à l’utilisation d’un moteur électrique pour chaque bande de cellules photovoltaïques, avec un système de transmission de mouvement comportant des réducteurs et des accouplements.
Complexité :
— Nombre de composants : n moteurs + n réducteurs + n éléments d’accouplement
— Nombre de liaisons : n systèmes complets indépendants Inconvénients :
— Complexité de liaisons élevée (coaxialité ..)
— nécessité d’entretien d’une maniere continue et consommation électrique plus élevée
Voici le schéma cinématique illustrant cette solution :

Figure 3.2 – Schéma cinématique de la solution avec Moteurs-accouplements

— Solution S12 : Consiste à utiliser un seul moteur électrique dont l’arbre est relié à une crémaillère (1), reliée à un système d’engrenages (2) pour chaque étage.
Complexité :
— Nombre de composants : 1 crémaillère + n pignons
— Nombre de liaisons : n pivots + 1 glissière
Inconvénients :
— Nous devons ajuster l’entraxe E et le module m
— Problèmes de lubrification et d’étanchéité, surtout à l’extérieur Voici le schéma cinématique illustrant cette solution :

31

Projet De Fin D’année

Figure 3.3 – Schéma cinématique de la solution avec crémaillère-pignons

— Solution S13 : Consiste à coupler un moteur avec un système de poulies-courroies : (1) poulies, (2) tiges, (3) courroies.
Complexité :
— Nombre de composants : n poulies + n tiges + n courroies
— Nombre de liaisons : (3n + 1) pivots + 2n encastrements Inconvénients :
— Risque de glissement, notamment en environnement extérieur (vent, pluie)
Voici le schéma cinématique illustrant cette solution :

Figure 3.4 – Schéma cinématique de la solution avec poulies-courroies

32

Projet De Fin D’année

— Solution S14 : Utilisation d’un vérin électrique dont la tige (1) est reliée à n biellettes (2), transmettant chacune un mouvement de rotation à une bande. Complexité :
— Nombre de composants : 1 tige de vérin + n biellettes
— Nombre de liaisons : 1 glissière + 3n pivots (ou pivots glissants) Inconvénients :
— Nombre de liaisons élevé
Voici le schéma cinématique illustrant cette solution :

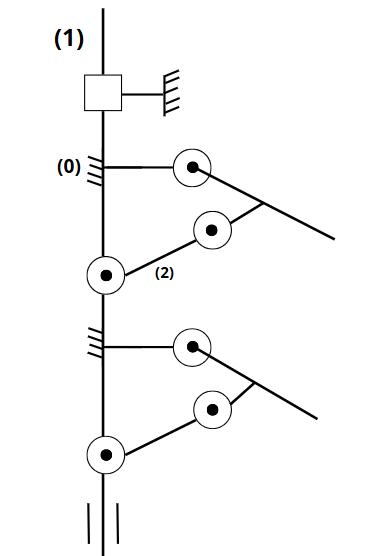
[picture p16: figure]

Figure 3.5 – Schéma cinématique de la solution avec Vérin électrique et biellettes

Après la réalisation d’une analyse comparative, nous avons retenu la solution S14 . Elle offre un bon compromis entre simplicité mécanique, performance, fiabilité et facilité d’assemblage pour atteindre notre objectif de plus elle est bien adaptée à l’utilisation en extérieur.

## 3.3 Développement de la solution retenue

### 3.3.1 Schéma global et dimensions du panneau

Voici le schéma global du panneau avec suiveur à 1 axe :

33

Projet De Fin D’année

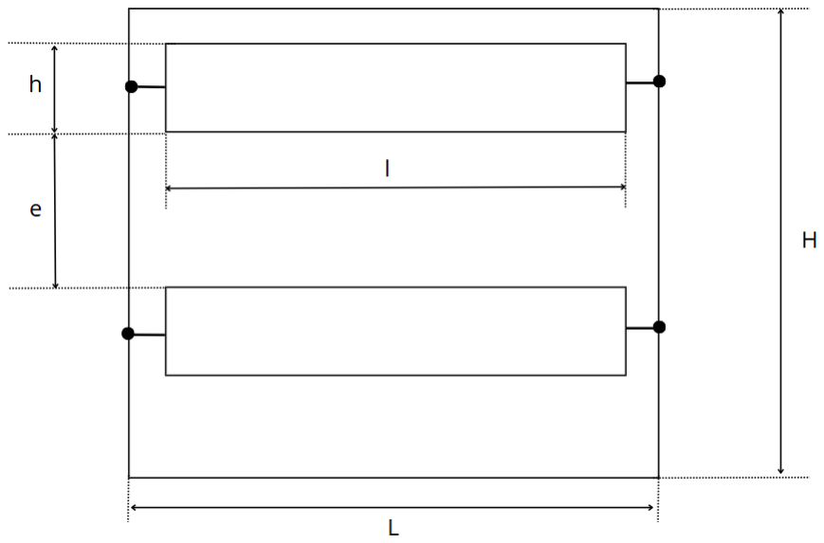
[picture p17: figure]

Figure 3.6 – Schéma global du panneau avec suiveur à 1 axe

Les dimensions principales à déterminer sont les suivantes :
— e : l’écart entre les bandes
— h : la hauteur des bandes
— l : la longueur des bandes
— L : la longueur totale du châssis
— H : la hauteur totale du châssis

### 3.3.2 Calcul des dimensions globales

Pour des raisons d’encombrement, il est préférable de fixer une inclinaison maximale βmax afin de limiter la rotation des bandes. De plus, pour réduire l’exposition des bandes aux facteurs extérieurs, nous devons choisir une distance maximale que ces dernières ne peuvent pas dépasser, dmax, choisie égale à 250 mm. En se référant à la figure ci-dessus, nous obtenons les relations suivantes :

dmax = h · sin(βmax) | (3.3.1)

e + h =

h
cos(βmax)

(3.3.2)

D’où on tire l’expression de e :

34

Projet De Fin D’année

e = h

1
cos(βmax)

− 1

!
(3.3.3)

Nous avons adopté ce calcul afin d’ajuster de manière optimale e et h d’où d’éviter tout problème d’ombrage possible entraînant une perte de rendement énergétique.

Pour dimensionner notre panneau mural avec suiveur, nous allons considérer comme référence une installation domestique type avec :
— une puissance installée de 1 kWc,
— une orientation plein sud avec un angle β = 45◦
,
— des cellules photovoltaïques ayant une production de 0,2 kWc/m² (soit un
rendement de l’ordre de 17%).
La surface de cette installation de référence est donc :

Sref =

1
0,2

= 5 m

2

L’énergie récupérée sur une année par cette installation est donnée par :

Erécupérée,ref = Erécupérable × rendement × Sref = 2400 × 0,17 × 5 = 2040 kWh

Pour que notre panneau mural avec suiveur puisse récupérer la même quantité d’énergie sur une année, la superficie de ses cellules doit vérifier :

Erécupérée,ref = Erécupérable,mural,suiveur × rendement × Ssuiveur

D’où :

Ssuiveur =

Erécupérée,ref
Erécupérable,mural,suiveur × rendement =

2040
2700 × 0,17

≈ 4,44 m

2

Si l’on devait assurer cette même production avec un panneau mural classique (incliné à β = 90◦
), la superficie des cellules serait :

Smural,fixe =

2040
1400 × 0,17

≈ 8,6 m

2

Conclusion comparative

— Un système avec suiveur permet de réduire la surface de cellules à environ 4.4 m² au lieu de 8.6 m²
: soit presque une division par 2. — Par rapport à une toiture inclinée fixe à 45◦
, le gain n’est pas significatif (0.5 m²), donc le suiveur est plus intéressant pour une installation plane.

35

Projet De Fin D’année

Choix des dimensions finales

À partir du calcul effectué précédemment, et dans le but de choisir β qui nous donne le maximum d’énergie récupérable tout en respectant le critère d’encombrement, nous déduisons que la surface des cellules photovoltaïques est située dans l’intervalle suivant :

Scellules ∈ [4.4, 5] m²

Retenons, dans ce qui suit, dmax = 250, mm :

Cas d’une inclinaison fixée à β = 45◦

h =

250
sin(45◦
)

≈ 353 mm

e = 353 ∗ (

1
cos(45◦
)

− 1) ≈ 146 mm

Dans ce cas θ = 30◦
, nous obtenons cos(θmax) est égale à 0,88

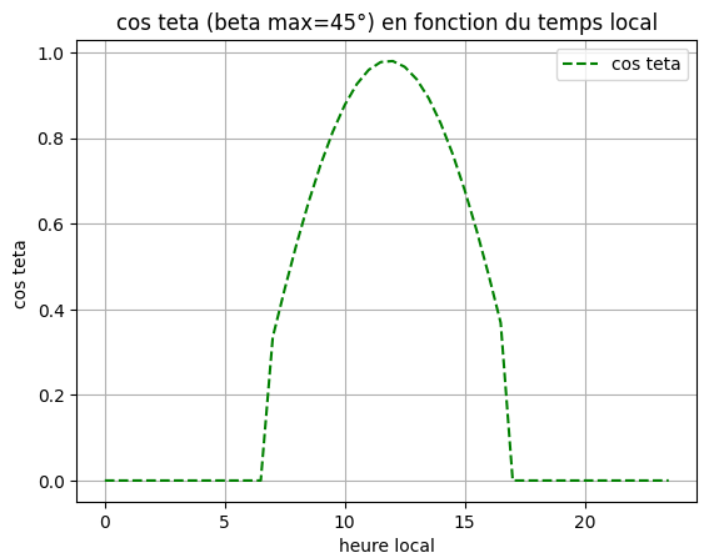
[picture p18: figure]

Figure 3.7 – Courbe représentative de cos(θ) dans le cas où β = 45◦

36

Projet De Fin D’année

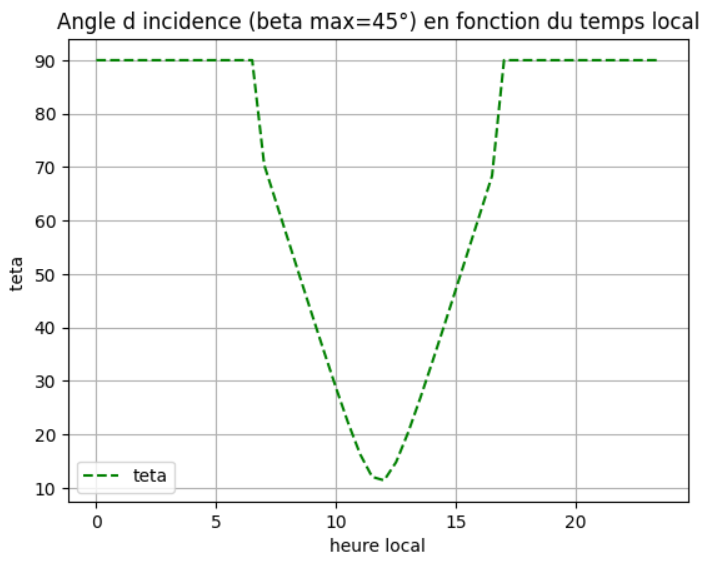
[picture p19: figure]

Figure 3.8 – Courbe représentative de l’Angle d’incidence dans le cas où β = 45◦

Cas d’une inclinaison fixée à β = 50◦

h =

250
sin(50◦
)

≈ 326 mm

e = 326 ∗ (

1
cos(50◦
)

− 1) ≈ 196 mm

Lorsque θ = 25◦
, la valeur de cos(θmax) est égale à 0,9

37

Projet De Fin D’année

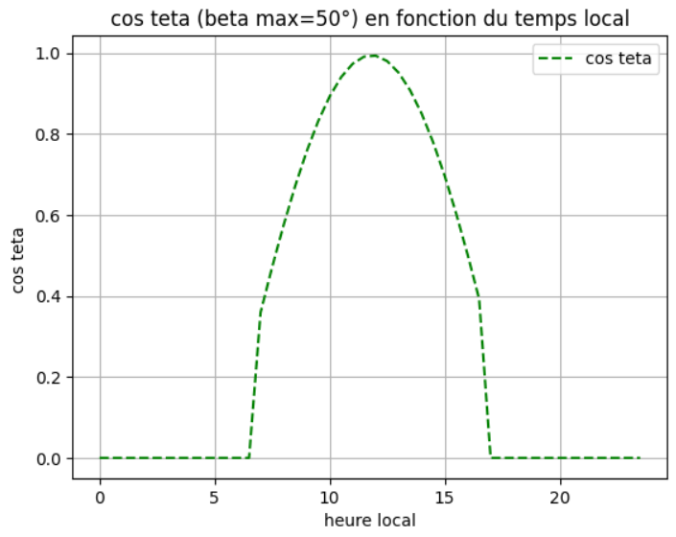
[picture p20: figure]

Figure 3.9 – Courbe représentative de cos(θ) dans le cas où β = 50◦

Figure 3.10 – Courbe représentative de l’Angle d’incidence dans le cas où β = 50◦

À partir des résultats tirés et en analysant les deux cas, nous avons choisi d’accorder la priorité au critère d’encombrement, puisque le gain en énergie annuelle récupérable n’est pas important.
De ce fait l’angle maximal d’inclinaison par rapport au sol choisi est βmax = 45◦ .

38

Projet De Fin D’année

### 3.3.3 Dimensionnement du dispositif de transformation de mouvement

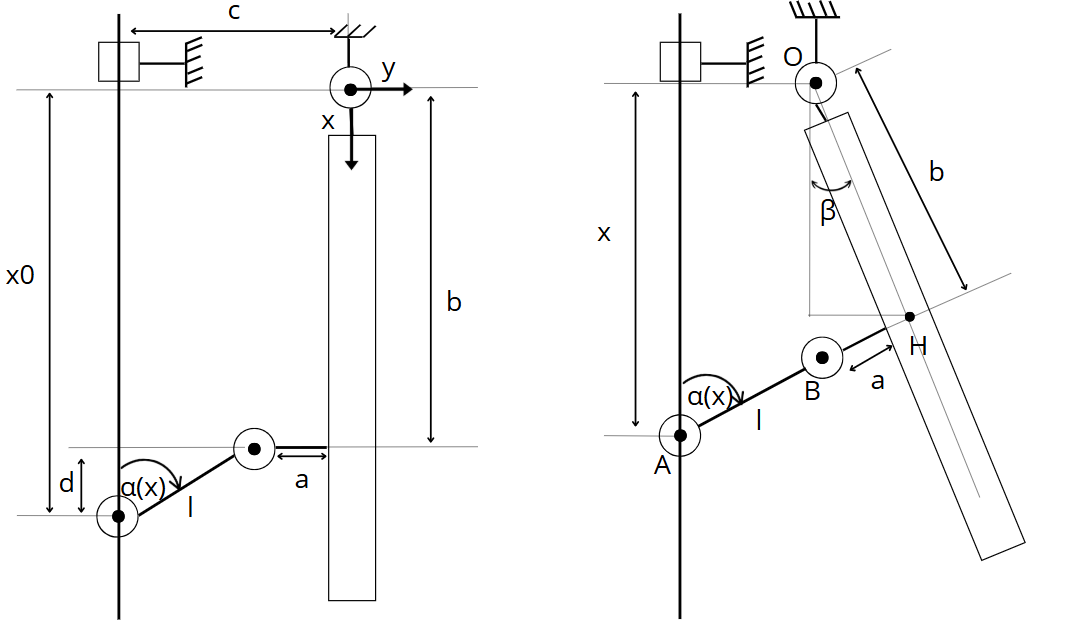
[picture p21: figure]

Figure 3.11 – Calcul des paramètres du panneau en fonction du déplacement x

Dans le but de déterminer α(x) : l’angle de rotation que la biellette peut effectuer et β(x) avec x : le déplacement et en exploitant la relation de Chasles, nous obtenons :
−−→OH =

−→OA +

−→AB +

−−→BH

Avec :

−→OA =
x
−c

!
;

−→AB =
−l cos α
lsin α

!
;

−−→BH =
−a sin β
a cos β

!
;

−−→OH =
b cos β
b sin β

!

Donc, en sommant :

−−→OH =

−→OA +

−→AB +

−−→BH

Cela donne :

b cos β
b sin β

!
=

x − l cos α − a sin β
−c + lsin α + a cos β

!

39

Projet De Fin D’année

Donc, le système :

(1) b cos β = x − l cos α − a sin β
(2) b sin β = −c + lsin α + a cos β

Afin de résourdre ce systeme obtenu on commence par l’isolation des les termes trigonométriques. À partir de la première équation, on obtient :

a sin β + b cos β = x − l cos α

et à partir de la deuxième :

−a cos β + b sin β = −c + lsin α

On exprime maintenant les fonctions trigonométriques. On isole sin β à partir de la première relation :

sin β =

x − l cos α − b cos β
a
et cos β à partir de la deuxième :

cos β =

c − lsin α + b sin β
a
On effectue une substitution de sin β dans l’expression de cos β :

cos β =

c − lsin α + b

x−l cos α−b cos β
a

a
ce qui donne, après simplification :

cos β =

a(c − lsin α) + b(x − l cos α) − b

2
cos β
a

2

En regroupant les termes :

a

2
cos β + b

2
cos β = a(c − lsin α) + b(x − l cos α)

ce qui conduit à l’expression suivante :

cos β =

b(x − l cos α) + a(c − lsin α)
a

2 + b

2

La valeur de β s’obtient alors par :

β = arccos

b(x − l cos α) + a(c − lsin α) a

2 + b

2

!

40

Projet De Fin D’année

Enfin, on peut aussi exprimer sin β de manière équivalente :

sin β =

a(x − l cos α) − b(c − lsin α) a

2 + b

2

On peut maintenant dimensionner la longueur des plaques de biellettes en écrivant l en fonction des autres paramètres qu’on va fixer :

l =

bx + ac − cos β(a

2 + b

2
)
b cos α + a sin α
On prend :
a | = 50 mm
b | = 186 cos(βmax)
x | = 306 mm
x0 | = 125,14 mm
c | = 227 mm
α | = 78.658◦

βmax = 45◦

En substituant dans l’équation précédente on trouve l∼ 290mm.
Le choix de C est pris de telle sorte on prend en considération l’encombrement de notre panneau et donc on a minimiser le maximum la valeur de C tout en respectant l’inclinaison des bandes de cellules.

## 3.4 Conception sur CATIA V5

Le but de cette partie consiste à expliquer le mécanisme de la solution retenue et les solution technologiques envisagées d’une manière généralisée et adaptable pour des différentes dimensions ,dans une étape plus avancée on peut faire une conception complète avec un calcul et un dimensionnement plus détaillés afin de choisir les bons actionneurs.

41

Projet De Fin D’année

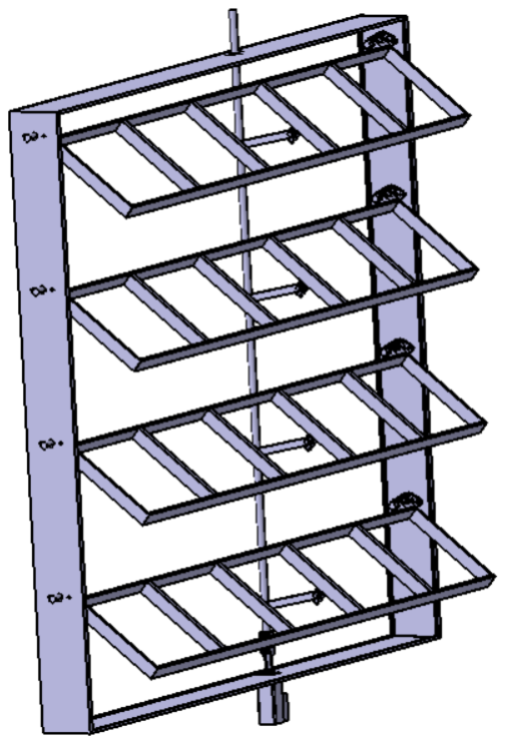
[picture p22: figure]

Figure 3.12 – Solution en CATIA

### 3.4.1 Description des composants principaux

Châssis :
Pour réduire le poids du panneau on a opté pour un châssis qui est sous forme de 4 profilés en "U" avec un chanfrein à l’extrémité soudés entre eux comme il est indiqué dans les deux figures suivantes :

42

Projet De Fin D’année

(a) châssis | (b) profilé en U

Figure 3.13 – châssis

Support :
Lors de la conception du support on doit assurer à la fois la résistance à la charge de flexion et la légèreté du composant pour faciliter le maintien des cellules et leur rotation,pour ce faire on a opté pour une configuration qui consiste à souder des tubes rectangulaires entre eux comme le montrent ces deux figures :
(a) support assemblé | (b) tube rectangulaire

Figure 3.14 – Support

43

Projet De Fin D’année

Paliers à rotules :

(a) Palier assemblé | (b) vue éclatée

Figure 3.15 – Palier à rotule

Les paliers à rotule constituent une solution fiable ,en effet, ils offrent un fonctionnement silencieux avec un entretien minimal tout en assurant des performances idéales dans un environnement extérieur puisqu’ils sont résistants à la corrosion. on trouve ci dessous d’autres spécifications sur les paliers utilisées dans notre solution :

matériau | plastique
diamètre d’arbre | 25mm
charge radiale statique | 3000N
charge axiale statique | 1500N
Angle de rotation | 15°
poids | 58.5g
intervalle de température | [-30°C ;80°C]

Table 3.2 – Caractéristiques des paliers [10].

44

Projet De Fin D’année

vérin électrique :

Figure 3.16 – Vérin électrique

Le choix du vérin est basé dans notre cas sur la course nécessaire, selon notre conception,on a choisi un vérin de référence "ESBF-BS-63-300-10P" ce vérin est caractérisé par une course de 300 mm et une force d’avance de 7000N [11] [12].

(a) Embout à rotule | (b) Fourchette filetée

Figure 3.17 – fourchette filetée et embout à rotule

### 3.4.2 Solutions technologiques

Afin d’assurer la rotation du support par rapport au châssis ,notre solution consiste à associer une liaison linéaire annulaire et une rotule des deux cotés : Liaison linéaire annulaire : cette liaison est assurée par un arrêt axial de l’arbre par rapport à la chape par l’intermédiaire d’un criclips et une entretoise avec un arrêt en translation aussi prévu entre le châssis est l’arbre,cette solution est schématisée dans les figures si dessous :

45

Projet De Fin D’année

(a) liaison schématisée | (b) Liaison modélisée en CATIA

Figure 3.18 – Liaison linéaire annulaire

Liaison rotule : il suffit de prévoir un arrêt axial de part et d’autre de la chape et laisser l’extrémité de l’arbre libre puisqu’on dispose des paliers à rotule cette liaison est détaillée dans les deux figures suivantes :

(a) liaison schématisée | (b) Liaison modélisée en CATIA

Figure 3.19 – Liaison rotule

Remarque :Nous avons pris en compte dans cette solution l’effet de la dilatation de l’arbre par la température et par suite on a prévu un jeu entre l’entretoise et le palier comme indiqué dans la figure suivante .

Figure 3.20 – jeu fonctionnel

Le mécanisme de notre dispositif consiste à transformer le mouvement de translation de la tige en une rotation du support,la solution envisagée est l’ensemble

46

Projet De Fin D’année

de deux articulations en introduisant un axe entre la tige et deux plaques de biellette arrêté axialement par deux cirlips comme le montrent les figures suivantes :

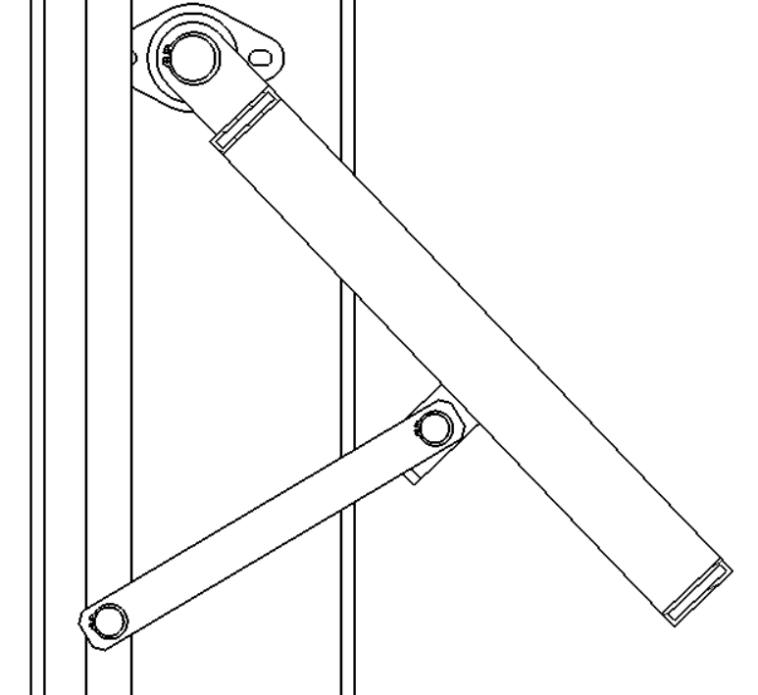
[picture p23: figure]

(a) mécanisme schématisé | (b) mécanisme modélisé en CATIA

Figure 3.21 – Mécanisme de la solution

La translation de la tige aussi doit être guidée et par suite nous visons à ce que son mouvement soit glissant par rapport au châssis ceci est fait par la présence d’un paliers à rotule fixé à la partie supérieure du châssis avec un ensemble assurant la translation de la tige

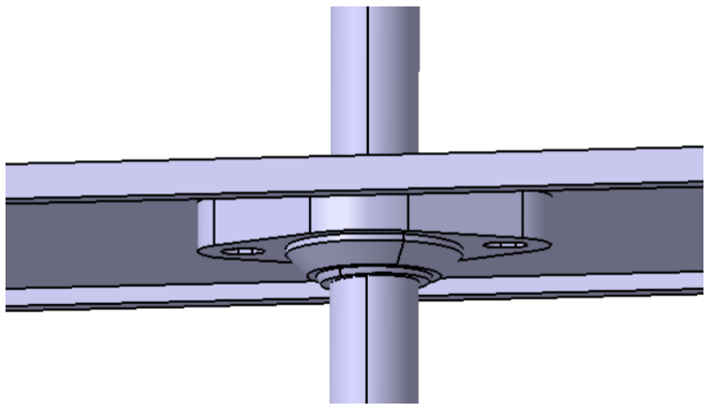
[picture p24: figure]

Figure 3.22 – guidage en translation

La translation de la tige se fait à partir d’un ensemble composé du vérin, un embout à rotule et une fourche filetée ces 3 composants sont liés entre eux comme le montre la Figure suivante [13] [14] [15] :

47

Projet De Fin D’année

Figure 3.23 – vue éclatée de l’ensemble

A l’état initial les bandes ne sont pas inclinées , le vérin est par suite actif avec une course de 205mm alors que le maximum d’inclinaison des bandes est atteint lorsque le vérin est à son état initial ces figures montrent la relation entre l’inclinaison des bandes et la course du vérin :

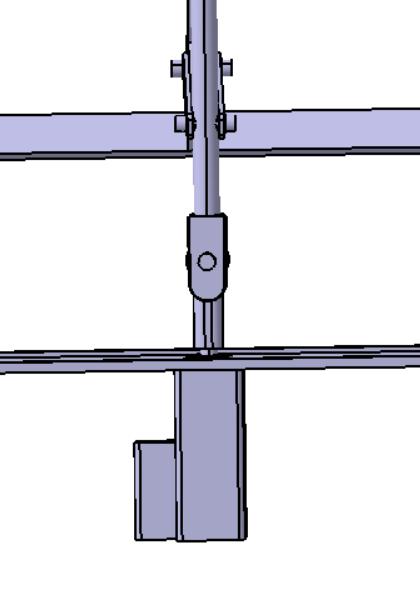
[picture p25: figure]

(a) Position du vérin | (b) Inclinaison maximale des bandes

Figure 3.24 – Panneau au cours de la journée

48

Projet De Fin D’année

(a) Position du vérin | (b) Position initiale des bandes

Figure 3.25 – Panneau au repos

49

Projet De Fin D’année

# Conclusion générale

Ce projet de fin d’année nous a permis d’optimiser la captation de l’énergie solaire en utilisant un système photovoltaïque mural innovant qui intègre un dispositif suiveur que nous avons développé. Face aux limites des panneaux muraux fixes, notamment en termes de rendement, nous avons proposé une solution permettant d’ajuster dynamiquement l’angle d’inclinaison du panneau selon l’élévation du soleil.

Nous avons d’abord établi un modèle analytique , puis développé une simulation numérique en Python pour évaluer l’énergie récupérable selon différentes configurations. Ces analyses ont montré l’intérêt d’un suivi à un axe, qui offre un bon compromis entre performance énergétique et simplicité mécanique.
La solution retenue, utilisant un vérin électrique et un système de biellettes, a été modélisée en détail sur CATIA V5, avec une attention particulière portée au dimensionnement, aux contraintes d’encombrement et aux conditions extérieures. Les résultats ont montré un gain significatif en énergie par rapport à une installation murale fixe, prouvant la pertinence de notre approche.

Ce travail constitue une contribution concrète à l’amélioration des systèmes solaires , en combinant efficacité énergétique, faisabilité mécanique et intégration architecturale.

50

Projet De Fin D’année

# Annexe

# Code Python

import numpy as np
import matplotlib . pyplot as plt from scipy . optimize import fminbound

def calcul_numero_jour ( mois , jours ) :
days_in_month = [31 , 28 , 31 , 30 , 31 , 30 , 31 , 31 , 30 , 31 , 30 , 31]
return sum ( days_in_month [: mois -1]) + jours

def calcul_angle_B ( Nj ) :
B = np . radians (0.98563 * ( Nj - 173) ) return B

def equation_du_temps ( Nj ) :
x = 360 * ( Nj - 1) / 365.242
EOT = (0.258 * np . cos ( np . radians ( x ) )
- 7.416 * np . sin ( np . radians ( x ) )
- 3.648 * np . cos (2 * np . radians ( x ) )
- 9.228 * np . sin (2 * np . radians ( x ) ) ) return EOT

def calcul_TSV ( heures , longitude_locale , longitude_fuseau , EOT ) :
LC = ( longitude_locale - longitude_fuseau ) / 15
TSV = heures - ( EOT / 60) + LC
return TSV

def calcul_angle_horaire ( TSV ) :
w = np . radians (15 * ( TSV - 12) ) return w

def calcul_declinaison ( B ) :

51

Projet De Fin D’année

decl = np . arcsin (0.39795 * np . cos ( B ) ) return decl

def calcul_elevation ( decl , latitude_locale , w ) :
alpha = np . arcsin ( np . sin ( decl ) * np . sin ( latitude_locale ) +
np . cos ( decl ) * np . cos ( latitude_locale ) * np . cos ( w ) )
alpha = np . where ( alpha < 0 , 0 , alpha )
return alpha

def calcul_azimut (w , decl , alpha , latitude_locale ) : A = np . zeros (len( w ) )
A1 = np . zeros (len ( w ) )
for i in range (len( w ) ) :
A [ i ] = np . arccos (( np . sin ( decl ) * np . cos ( latitude_locale ) -
np . cos ( decl ) * np . cos ( w [ i ]) * np . sin ( latitude_locale ) ) /
( np . cos ( alpha [ i ]) ) )
if np . sin ( w [ i ]) >= 0:
A1 [ i ] = 2 * np . pi - A [ i ] else :
A1 [ i ] = A [ i ]
return A1

def calcul_A_he ( y ) :
return np . sin ( np . radians ((360 / 365) * ( y - 121) ) )

def calcul_T0 ( latitude_locale , A_he , z , alpha ) :
alpha = np . array ( alpha )
t00 = 2.4 - 0.9 * np . sin ( latitude_locale ) + 0.1 * (2 + np . sin ( latitude_locale ) ) * A_he - 0.2 * z - (1.22 + 0.14 * A_he ) * (1 - np . sin ( alpha ) )
return t00

def calcul_T1 ( z ) :
return (0.89) ** z

def calcul_T2 ( A_he , z ) :
return (0.9 + 0.4 * A_he ) * (0.63) ** z

def _cos_teta ( alpha , beta , gamma , A ) :

52

Projet De Fin D’année

valeur = np . sin ( alpha ) * np . cos ( beta ) + np . cos ( alpha ) * np . sin ( beta ) * np . cos ( gamma - A )
return np . maximum ( valeur , 0)

def calcul_ILi ( I_0 , Tl , z , alpha ) :
alpha = np . array ( alpha )
IL = np . zeros ( np . shape ( alpha ) ) termeexpo = np . zeros ( np . shape ( alpha ) ) x = np . zeros ( np . shape ( alpha ) )
for j in range (len( w ) ) :
if alpha [ j ] == 0:
IL [ j ] = 0
else :
x [ j ] = (9.4 * np . sin ( alpha [ j ]) ) / (0.89 ** z ) termeexpo [ j ] = np . exp ( - Tl [ j ] * (1 / (0.9 + x [ j ]) ) )
IL [ j ] = I_0 * termeexpo [ j ]
return IL

def _ILinc ( ILi , cos_teta ) :
ILinc = ILi * cos_teta
ILinc = np . where ( ILinc <= 0 , 0 , ILinc ) return ILinc

def integrale_ILi_trapz ( heures , ILinc ) : return np . trapezoid ( ILinc , heures )

def calcul_energie_annuelle ( latitude_locale , longitude_locale , longitude_fuseau , z , I_0 , gamma , m ) : energie_totale = 0
days_in_month = [31 , 28 , 31 , 30 , 31 , 30 , 31 , 31 , 30 , 31 , 30 , 31]
for month in range (1 , 13) :
for day in range (1 , days_in_month [ month -1] + 1) :
y1 = calcul_numero_jour ( month , day )
heuress = np . arange (0 , 24 , 0.5)
EOT1 = equation_du_temps ( y1 )
TSV1 = calcul_TSV ( heuress , longitude_locale , longitude_fuseau , EOT1 )
w1 = calcul_angle_horaire ( TSV1 )
decl1 = calcul_declinaison ( calcul_angle_B ( y1 ) ) alphai = calcul_elevation ( decl1 , latitude_locale , w1 )

53

Projet De Fin D’année

A1 = calcul_azimut ( w1 , decl1 , alphai , latitude_locale )
A_he1 = calcul_A_he ( y1 )
T00 = calcul_T0 ( latitude_locale , A_he1 , z , alphai )
T10 = calcul_T1 ( z )
T20 = calcul_T2 ( A_he1 , z )
Tl0 = T00 + T10 + T20
ILi1 = calcul_ILi ( I_0 , Tl0 , z , alphai )
if m == 0:
beta = np . full_like ( alphai , np . pi / 4) else :
beta = max_beta ( alphai , gamma , A1 ) cos_teta_ = _cos_teta ( alphai , beta , gamma , A1 ) ILinc0 = _ILinc ( ILi1 , cos_teta_ )
daily_energy = np . trapezoid ( ILinc0 , heuress ) energie_totale += daily_energy
return energie_totale / 1000

def max_beta ( alpha , gamma , A ) : beta = np . zeros (len ( alpha ) )
for i in range (len( alpha ) ) :
beta [ i ] = np . arctan2 ( np . cos ( alpha [ i ]) * np . cos ( gamma
- A [ i ]) , np . sin ( alpha [ i ]) )
beta [ i ] = np . clip ( beta [ i ] , 0 , np . radians (180) )
if alpha [ i ] == 0:
beta [ i ] = 0
return beta

54

Projet De Fin D’année

# Bibliographie

[1] Statistiques de la situation actuelle en tunisie, 2025 http://www.tunisieindustrie.gov.tn/upload/ENR/Guide_detaille_ENR_tunisie_mai2019.pdf (http://www.tunisieindustrie.gov.tn/upload/ENR/Guide_detaille_ENR_tunisie_mai2019.pdf) consulté le 10/01/2025
[2] Structure et fonctionnement d’une cellule PV https://www.researchgate.net/publication/330456824_Operation_and_physics_of_photovoltaic_solar_cells_an_overview (https://www.researchgate.net/publication/330456824_Operation_and_physics_of_photovoltaic_solar_cells_an_overview) consulté le 15/01/2025
[3] Structure | d’une | cellule | PV | https://www.lumensol.fr/
lumensol-solaire-photovoltaique-donnees-techniques.html (https://www.lumensol.fr/lumensol-solaire-photovoltaique-donnees-techniques.html) consulté le 15/01/2025
[4] Effet photovoltaïque sur une cellule PV https://www.annabac.com/revision-bac/le-photovoltaique-pour-capter-l-energie-solaire (https://www.annabac.com/revision-bac/le-photovoltaique-pour-capter-l-energie-solaire) consulté le 20/01/2025
[5] Power From The Sun de William B. Stine et Michael Geyer http://powerfromthesun.net/book.html consulté le 20/01/2025
[6] Les orbites de la Terre en relation avec le Soleil https://fr.wikipedia.org/wiki/Orbite_de_la_Terre (https://fr.wikipedia.org/wiki/Orbite_de_la_Terre) consulté le 28/01/2025
[7] Modèle de Capderou Kasten https://www.cder.dz/download/Art2-2_1.pdf consulté le 02/02/2025
[8] Les différents types de rayonnement solaire https://www.researchgate.net/publication/285322379_Modelisation_des_parametres_de_la_conversion_thermique_de_l’energie_solaire (https://www.researchgate.net/publication/285322379_Modelisation_des_parametres_de_la_conversion_thermique_de_l'energie_solaire) consulté le 02/02/2025
[9] Les différents types de rayonnement solaire https://www.researchgate.net/publication/285322379_Modelisation_des_parametres_de_la_conversion_thermique_de_l’energie_solaire (https://www.researchgate.net/publication/285322379_Modelisation_des_parametres_de_la_conversion_thermique_de_l'energie_solaire) consulté le 02/02/2025
[10] Caractéristiques des paliers https://maedlernorthamerica.com/partshop/flange-block-bearing-igus-igubal-efom-25-2-mounting-holes-bore-25mm-pn-62155125/ (https://maedlernorthamerica.com/partshop/flange-block-bearing-igus-igubal-efom-25-2-mounting-holes-bore-25mm-pn-62155125/)

55

Projet De Fin D’année

[11] Vérin électrique https://www.festo.com/in/en/a/download-document/datasheet/574098 (https://www.festo.com/in/en/a/download-document/datasheet/574098)
[12] Vérin | électrique | https://www.festo.com/media/catalog/203032_
documentation.pdf (https://www.festo.com/media/catalog/203032_documentation.pdf)
[13] Fourchette filetée https://www.festo.com/in/en/a/download-document/datasheet/10768 (https://www.festo.com/in/en/a/download-document/datasheet/10768)
[14] Embout à rotule https://www.festo.com/in/en/a/download-document/datasheet/9263 (https://www.festo.com/in/en/a/download-document/datasheet/9263)
[15] Guide d’assemblage de l’ensemble https://www.festo.com/media/catalog/203517_documentation.pdf (https://www.festo.com/media/catalog/203517_documentation.pdf)

56

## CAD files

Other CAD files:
projet PFA/ANSI_B27_7M_3AM1_17_STEEL_EXTERNAL_BASIC_DUTY_RETAINING_RING.CATPart
projet PFA/ANSI_B27_7M_3AM1_26_STEEL_EXTERNAL_BASIC_DUTY_RETAINING_RING.CATPart
projet PFA/ANSI_B27_7M_3AM1_32_STEEL_EXTERNAL_BASIC_DUTY_RETAINING_RING.CATPart
projet PFA/CorpsPalier.CATPart
projet PFA/PalierIgus.CATProduct
projet PFA/Spherepalier.CATPart
projet PFA/arbre.CATPart
projet PFA/assemblage.CATProduct
projet PFA/axeee.CATPart
projet PFA/baarre + palier.CATProduct
projet PFA/barre 2.0.CATPart
projet PFA/barre a l extremite.CATPart
projet PFA/barre au milieu.CATPart
projet PFA/barre inerieure.CATPart
projet PFA/barre longue.CATPart
projet PFA/barre4.0.CATPart
projet PFA/charniereee.CATPart
projet PFA/circlips axe.CATProduct
projet PFA/circlips bielette.CATProduct
projet PFA/paliers+chassis.CATProduct
projet PFA/part1.CATProduct
projet PFA/piece petite.CATPart
projet PFA/support H.CATProduct
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

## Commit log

2026-01-20 Simulation python de la trajectoire du soleil
    Cette simulation vise à suivre la trajectoire du soleil et à calculer le rendement du panneau toute au long de la journée il suffit de prendre comme paramètres d'entrée l'angle de rotation maximale e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
2026-01-20 Fichiers CAO
    [ANSI_B27_7M_3AM1_17_STEEL_EXTERNAL_BASIC_DUTY_RETAINING_RING.CATPart, ANSI_B27_7M_3AM1_26_STEEL_EXTERNAL_BASIC_DUTY_RETAINING_RING.CATPart, ANSI_B27_7M_3AM1_32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]
